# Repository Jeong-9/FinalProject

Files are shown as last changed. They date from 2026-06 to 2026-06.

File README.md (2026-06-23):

# ChemiBot - 비접촉 화학 실험 자동화 및 안전 관제 시스템





- **프로젝트명**: chemibot 비접촉 화학 실험 자동화 및 안전 관제 시스템
- **형태**: 팀 프로젝트
- **개발 인원**: 5명

## 프로젝트 개요 
유해 물질 노출 위험이 있는 화학 실험 환경에서, 연구자가 로봇팔을 원격 제어해 실험을 수행하는 비접촉 실험실 자동화 시스템

## 프로젝트 목적 
유해 화학물질 취급 과정에서 발생할 수 있는 안전사고를 예방하고, 손동작·얼굴 및 시선 추적 기반의 직관적인 인터페이스를 통해 연구자의 조작 편의성과 실험 효율을 향상시키는 것을 목표로 함

## 주요 기능
- 손동작 인식을 통한 로봇팔 제어.
- 얼굴 방향 추적을 통한 화면 내 시험관대 선택.
- 가스, 온도, 습도 기반 실시간 환경 모니터링.
- 실험실 및 보안실 모니터링 WPF 프로그램.
- React 기반 관리자 웹 화면.
- 스위치, 가스누출, 쓰러짐 감지를 통한 비상정지 기능.

# 개발 환경 및 사용 언어
- **개발 환경**: Visual Studio Code/Visual Studio
- **사용 언어**: C#, C++, Python
- **S/W 제작**: WPF, Flask, React
- **사용 라이브러리**: MediaPipe, OpenCV, RandomForest

- **통신**: TCP/IP, UDP, Socket.IO (WebSocket 기반), HTTP, UART Serial
- **임베디드 및 데이터베이스**: myCobot 280, Raspberry Pi 4B (myCobot 내장), Arduino Uno, MySQL

# 하드웨어 구성도 
 

# 시스템 구성


# 실험실 모니터링 프로그램 GUI 흐름도


# 비상 흐름도


## 담당 역할

- 실험실 아크릴 박스 3D 모델링 및 2D 제작 도면을 작성.
- 아크릴판 재단 및 실험실 아크릴 박스를 제작.
- Raspberry Pi 기반 내부문 및 잠금장치 서보모터 제어 코드를 작성.
- C# WPF 기반 보안실 모니터링 화면을 구현.
- TCP를 기반으로 실험실 웹캠 영상을 수신 받아 보안실 화면에 띄우고, UDP 기반의 비상 신호를 처리.
- UDP를 기반으로 보안실 마이크 음성을 송신해서 실험실 스피커에 출력하는 기능 구현.

## 담당 구현 파일

| 파일 | 설명 |
|---|---|
| `LabSafetyManager/MainWindow.xaml` | 보안실 WPF 화면 UI 구성 |
| `LabSafetyManager/MainWindow.xaml.cs` | 영상 출력, 비상 처리, 상태 표시, 로그, 버튼 이벤트 처리 |
| `LabSafetyManager/FallTcpClient.cs` | TCP 기반 영상 수신 및 UDP 기반 비상 신호 처리 |
| `LabSafetyManager/IntercomService.cs` | 보안실 PC 마이크 음성을 UDP 기반으로 전송 |
| `LabSafetyManager/LogEntry.cs` | 이벤트 로그의 시간, 위험 단계, 메시지 관리 |
| `Servo/door_control.py` | 내부문 및 잠금장치 서보모터 제어 |
| `Servo/door_server.py` | TCP 기반 서보모터 제어 명령 수신 |
| `lab_intercom.py` | UDP 기반 음성 수신 및 실험실 스피커 음성 출력 |

# 구현한 하드웨어 기능
## 1. 실험실 아크릴 박스 설계 및 제작 준비


- Solid Edge를 사용해 실험실 아크릴 박스의 전체 구조를 3D 모델링했습니다. 로봇팔 동작 범위와 실험 도구 배치 공간을 고려해 각 판의 크기를 설계했습니다.
## 2. 2D 설계도면 작성 


- 완성된 3D 모델링을 참고해서 각 판의 설계도면을 .dxf 파일 형식으로 변환했습니다. 각 판의 치수와 경첩 구멍 위치, 문 위치를 표시했습니다.

## 3. 아크릴 재단 및 제작


- 완성된 도면을 기준으로 아크릴판을 재단하고 실제 실험 공간을 제작했습니다. 여기서 내부 유해 물질이 외부로 빠져나가는 것을 방지하기 위해 외부 문과 내부 문으로 구성된 이중문 구조로 설계하고 제작했습니다.

## 4. 이중문 - 잠금장치, 내부 문 서보모터 제어

### 잠금장치


### 내부 문 모터


- 라즈베리파이에서 `pigpio`를 이용해 내부문 서보모터 2개와 잠금장치 서보모터를 제어했습니다.
- 내부문 1은 GPIO18, 내부문 2는 GPIO13, 잠금장치는 GPIO19에 연결했습니다.
- 각 모터의 열림·닫힘 위치를 직접 테스트하여 PWM 펄스폭 값을 설정했습니다.
- `door_server.py`는 TCP를 통해 명령을 수신하고, `door_control.py`의 서보 동작 함수와 연결합니다.
- 실험 시작, 내부문 열림·닫힘, 잠금 해제·복귀 명령을 구분하여 실행하도록 구현했습니다.
- 내부문 열림 명령이 들어올 때 잠금장치가 잠기지 않은 상태라면, 먼저 잠금장치를 잠근 뒤 내부문을 열도록 구성했습니다. 이를 통해 실험 공간이 외부에 직접 노출되지 않도록 했습니다.
- 실험 종료 후에는 내부문을 닫은 뒤 사용자가 시약관을 회수할 수 있도록 잠금 해제 명령을 별도로 구성했습니다.

# 구현한 소프트웨어 기능

## 1. 보안실 화면
### 평상시 보안실 화면


### 보안실 화면 버튼 기능

  

- 보안실 화면은 C# WPF를 활용하여 제작했습니다.
- 중앙 카메라 영역은 실험실 측 PC에서 전송한 웹캠 영상을 TCP로 수신하여 실시간으로 출력합니다.
- 이벤트 로그는 TCP 연결, 비상 감지, 경고 해제, 음성 송신 등 주요 이벤트를 시간 순서대로 기록합니다. 정보·주의·위험 단계에 따라 색상을 구분하여 표시합니다.
- 시스템 상태에서 카메라 연결 상태와 비상 상태 여부를 확인할 수 있습니다.
- 버튼 기능에서 경고 해제 버튼을 누르면 보안실 WPF의 비상 화면과 사이렌을 종료하고, UDP로 비상 해제(clear) 신호를 전송하여 통제실 감지 상태를 초기화합니다
- 로그 저장 버튼은 이벤트 로그에 기록된 모든 상태와 감지 시각을 .txt 파일로 저장할 수 있습니다.

## 2. 비상상황 발생 시 비상 신호 수신 및 음성 안내
### 비상 상황 발생 시 보안실 화면
  

### 보안실 관리자의 마이크 음성 안내
  

- 비상상황 발생 시 보안실 PC와 연결된 마이크를 통해 안내방송을 할 수 있습니다. 이 음성은 보안실에서 실험실 스피커로 전달되도록 구현했습니다.
- 비상 신호는 UDP로 수신하며, GAS_SENSOR, EME_BUTTON, FALL_DOWN 값을 통해 가스 감지, 비상 버튼, 쓰러짐 감지를 구분합니다.
- 실험실의 lab_intercom.py는 UDP로 수신한 보안실 음성을 실험실 스피커로 출력하도록 구현했습니다.
- 비상상황이 종료되면, 보안실 마이크 음성 수신도 종료되도록 구현했습니다.

# 시연 영상
https://youtu.be/Ujo4n_t4xfY

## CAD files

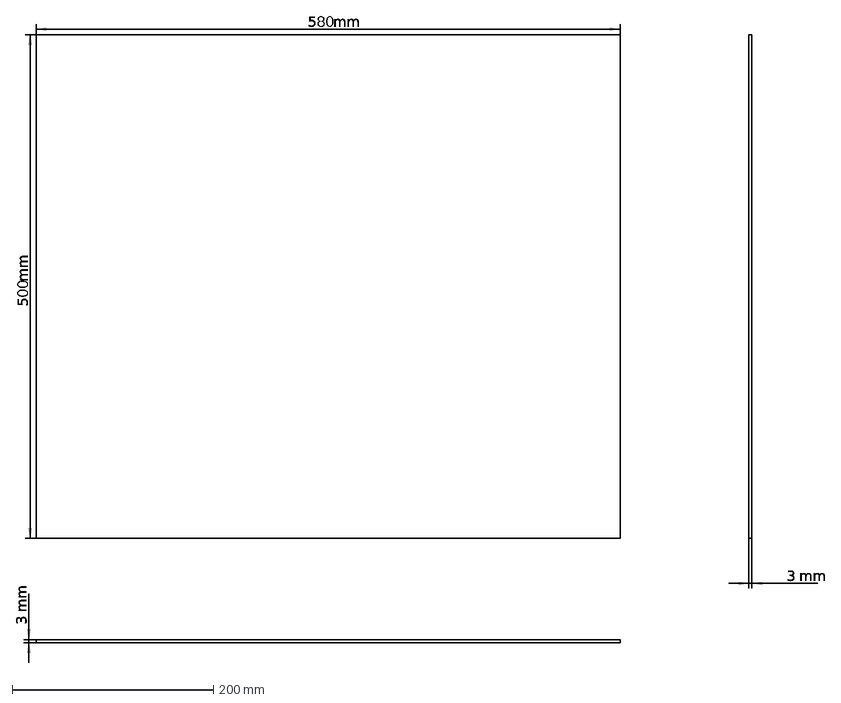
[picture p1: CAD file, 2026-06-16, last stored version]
Acrylic Plate Design Chart/아크릴 판 옆면.dxf
580
mm
500
3

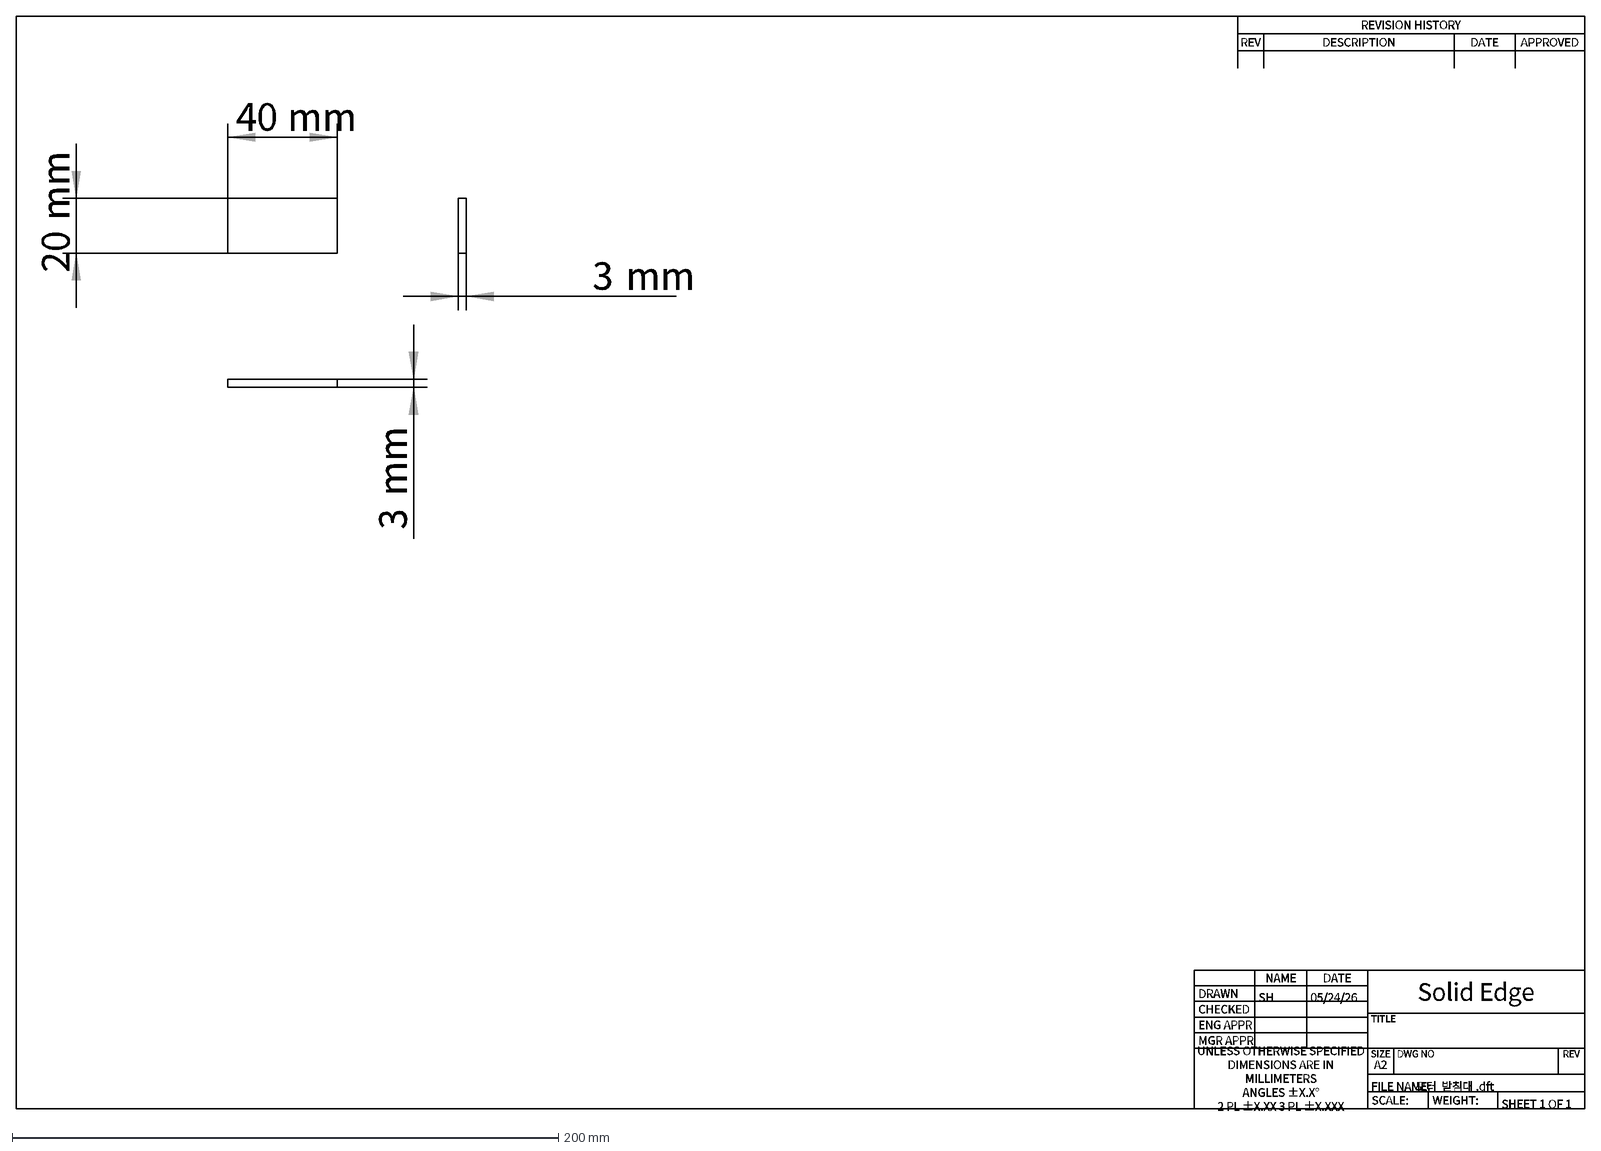
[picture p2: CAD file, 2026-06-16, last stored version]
모터 받침대.dxf
40
mm
20
3
DRAWN
CHECKED
ENG APPR
MGR APPR
UNLESS OTHERWISE SPECIFIED DIMENSIONS ARE IN MILLIMETERS ANGLES ±X.X° 2 PL ±X.XX 3 PL ±X.XXX
NAME
SH
DATE
05/24/26
Solid Edge
TITLE
SIZE
A2
DWG NO
REV
FILE NAME:
모터
받침대
.dft
SCALE:
WEIGHT:
SHEET 1 OF 1
REVISION HISTORY
DESCRIPTION
APPROVED

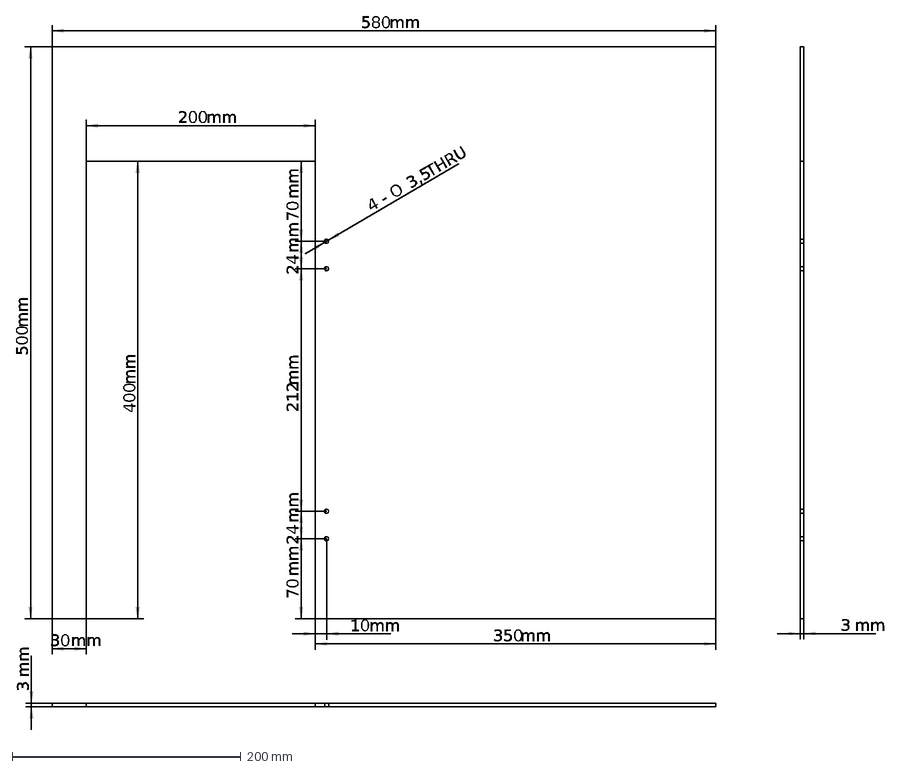
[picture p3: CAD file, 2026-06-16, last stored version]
Acrylic Plate Design Chart/아크릴 판 이중 문 구멍.dxf
580
mm
500
30
200
400
O
3,5
4 -
THRU
70
24
212
3
350
10

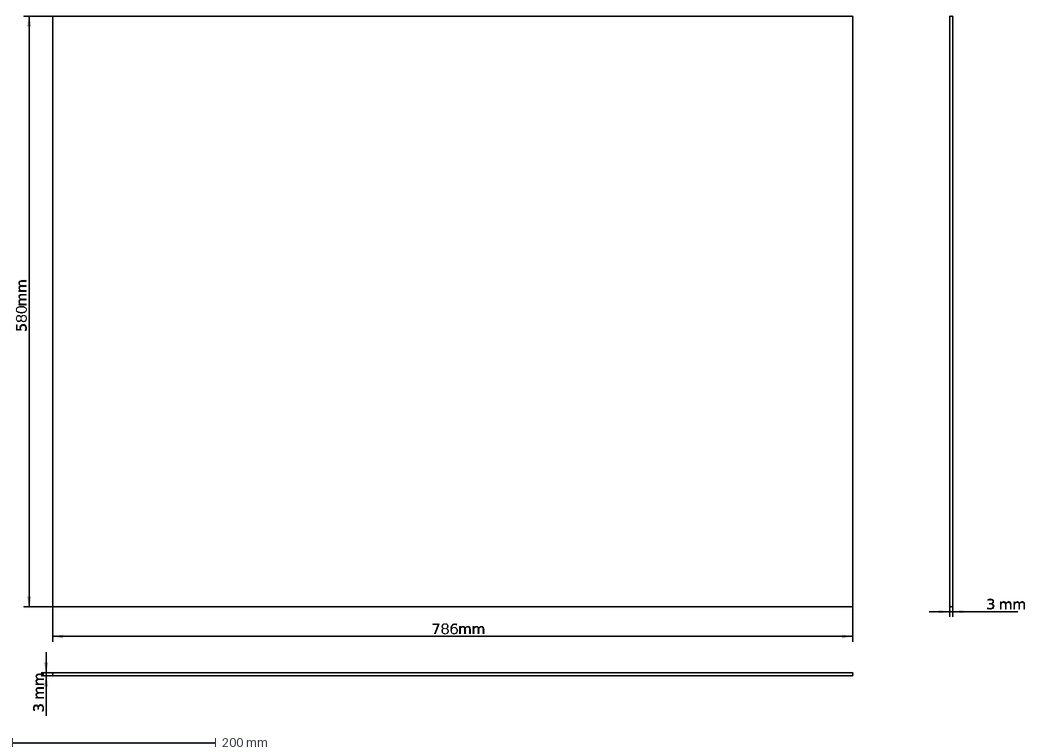
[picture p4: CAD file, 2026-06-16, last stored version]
Acrylic Plate Design Chart/아크릴 판 윗면.dxf
786
mm
580
3

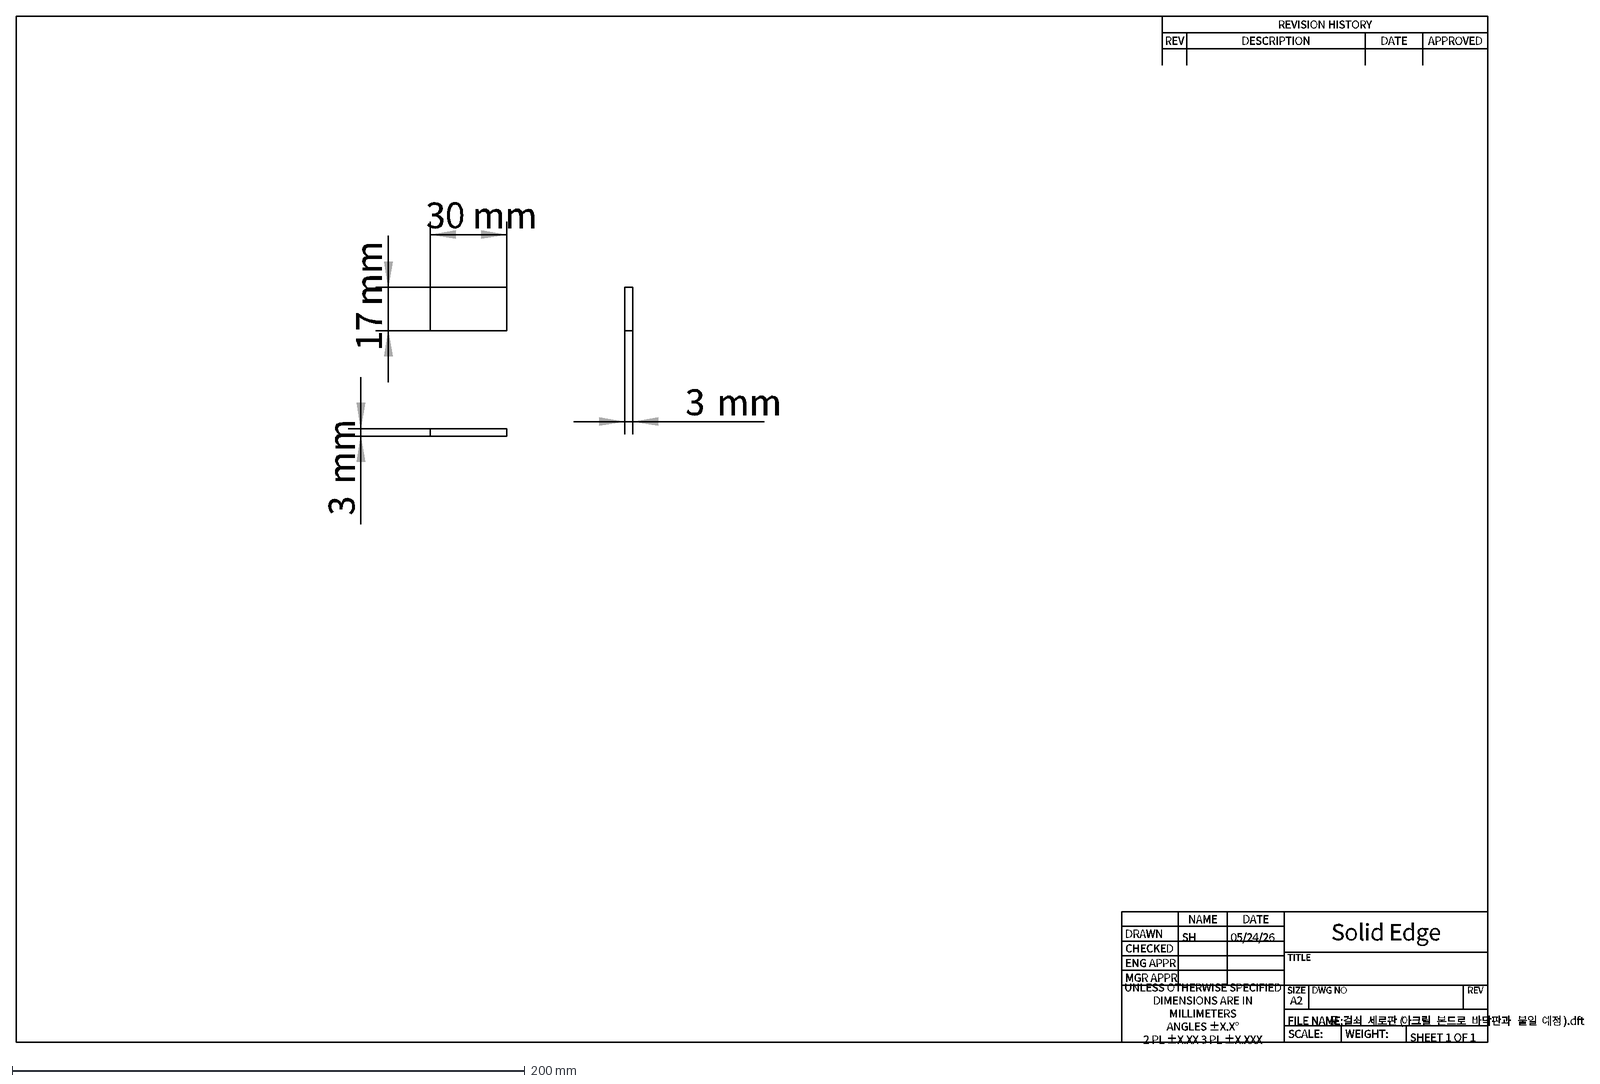
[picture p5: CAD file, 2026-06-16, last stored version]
Acrylic Plate Design Chart/문 걸쇠 세로판(아크릴 본드로 바닥판과 붙일 예정).dxf
30
mm
17
3
DRAWN
CHECKED
ENG APPR
MGR APPR
UNLESS OTHERWISE SPECIFIED DIMENSIONS ARE IN MILLIMETERS ANGLES ±X.X° 2 PL ±X.XX 3 PL ±X.XXX
NAME
SH
DATE
05/24/26
Solid Edge
TITLE
SIZE
A2
DWG NO
REV
FILE NAME:
문
걸쇠
세로판
(
아크릴
본드로
바닥판과
붙일
예정
).dft
SCALE:
WEIGHT:
SHEET 1 OF 1
REVISION HISTORY
DESCRIPTION
APPROVED

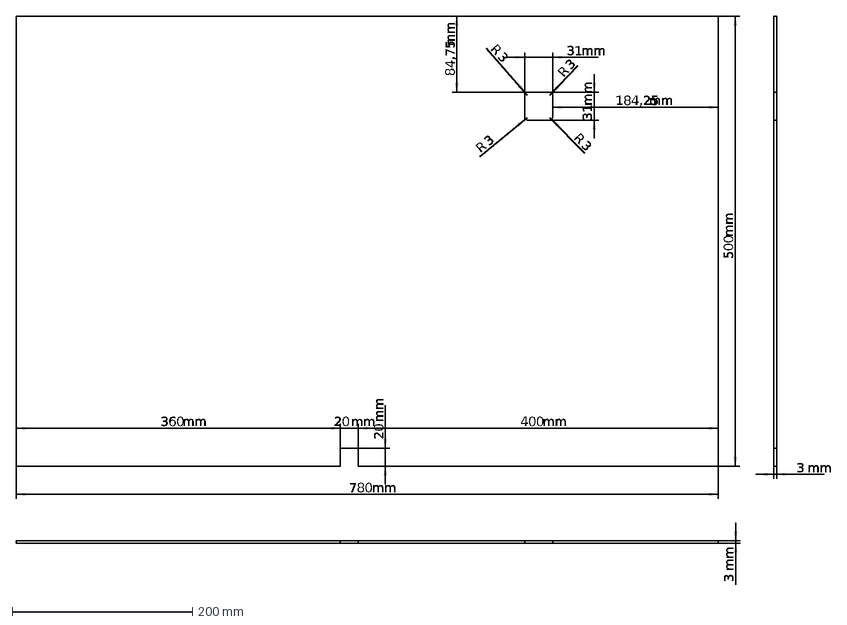
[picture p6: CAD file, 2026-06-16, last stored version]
Acrylic Plate Design Chart/아크릴 판 뒷면.dxf
360
mm
400
20
31
R
3
184,25
84,75
500
780

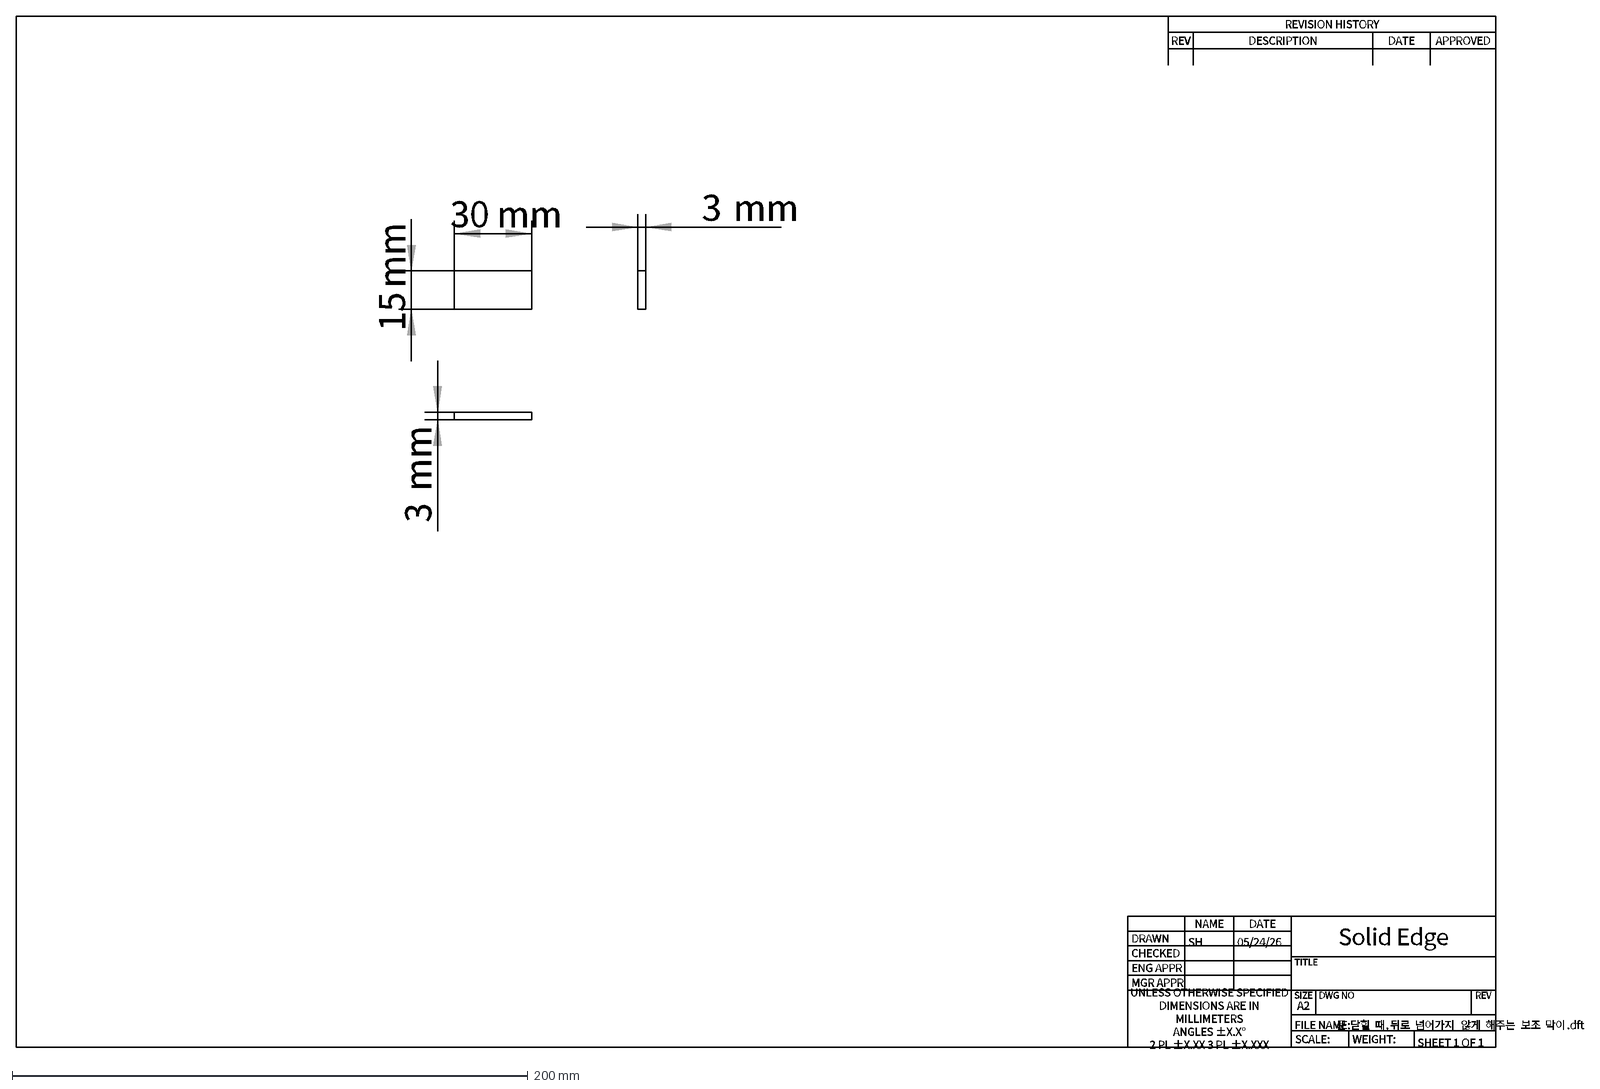
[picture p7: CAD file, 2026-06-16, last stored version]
Acrylic Plate Design Chart/문 닫힐 때, 뒤로 넘어가지 않게 해주는 보조 막이.dxf
30
mm
15
3
DRAWN
CHECKED
ENG APPR
MGR APPR
UNLESS OTHERWISE SPECIFIED DIMENSIONS ARE IN MILLIMETERS ANGLES ±X.X° 2 PL ±X.XX 3 PL ±X.XXX
NAME
SH
DATE
05/24/26
Solid Edge
TITLE
SIZE
A2
DWG NO
REV
FILE NAME:
문
닫힐
때
,
뒤로
넘어가지
않게
해주는
보조
막이
.dft
SCALE:
WEIGHT:
SHEET 1 OF 1
REVISION HISTORY
DESCRIPTION
APPROVED

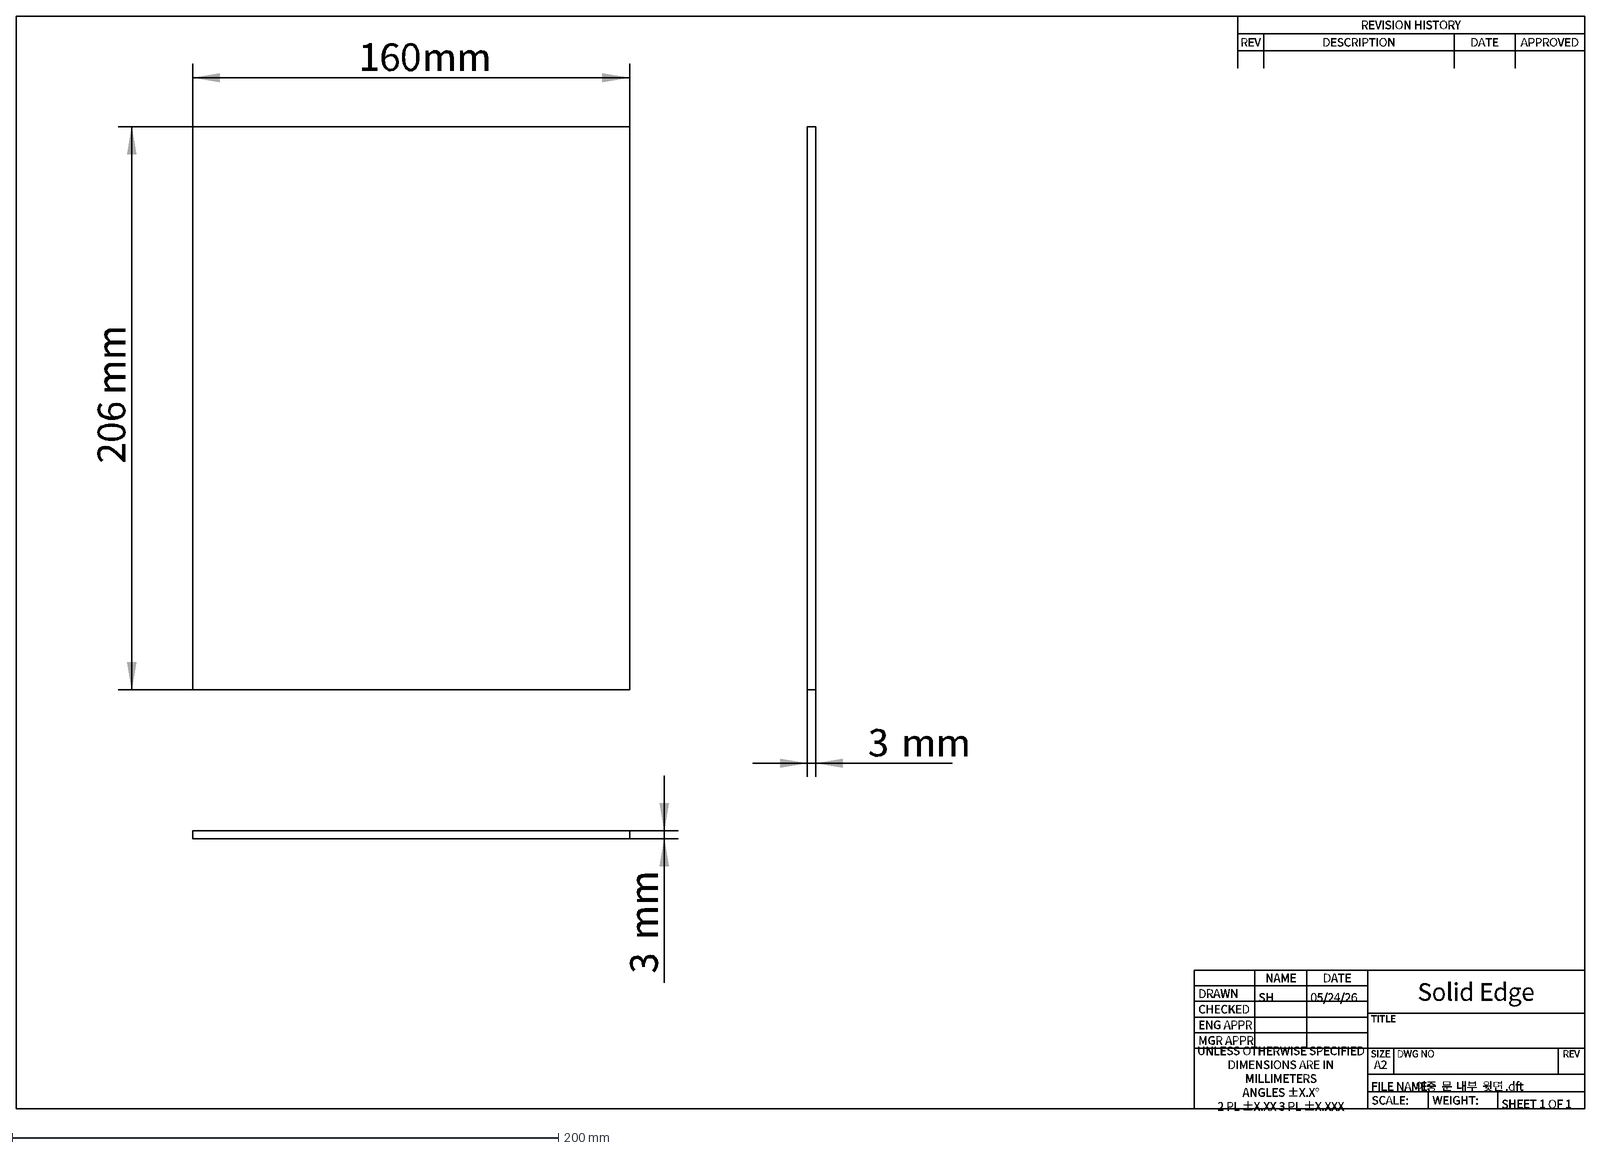
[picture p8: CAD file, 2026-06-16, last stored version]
Acrylic Plate Design Chart/이중 문 내부 윗면.dxf
160
mm
206
3
DRAWN
CHECKED
ENG APPR
MGR APPR
UNLESS OTHERWISE SPECIFIED DIMENSIONS ARE IN MILLIMETERS ANGLES ±X.X° 2 PL ±X.XX 3 PL ±X.XXX
NAME
SH
DATE
05/24/26
Solid Edge
TITLE
SIZE
A2
DWG NO
REV
FILE NAME:
이중
문
내부
윗면
.dft
SCALE:
WEIGHT:
SHEET 1 OF 1
REVISION HISTORY
DESCRIPTION
APPROVED

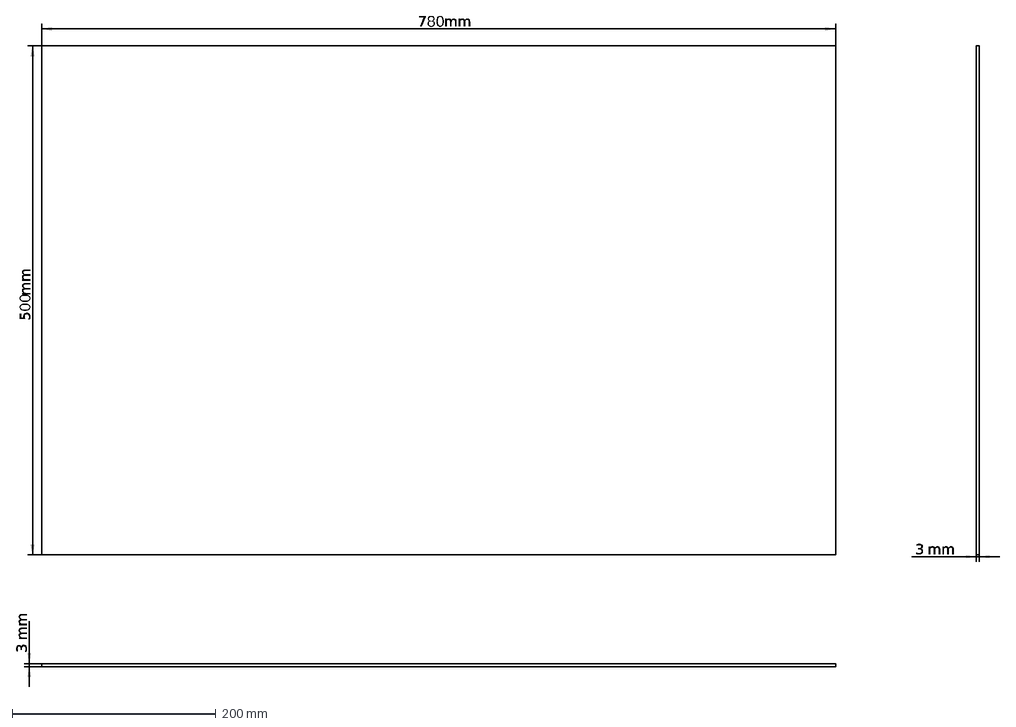
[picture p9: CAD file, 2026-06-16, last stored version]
Acrylic Plate Design Chart/아크릴 판 앞면.dxf
780
mm
500
3

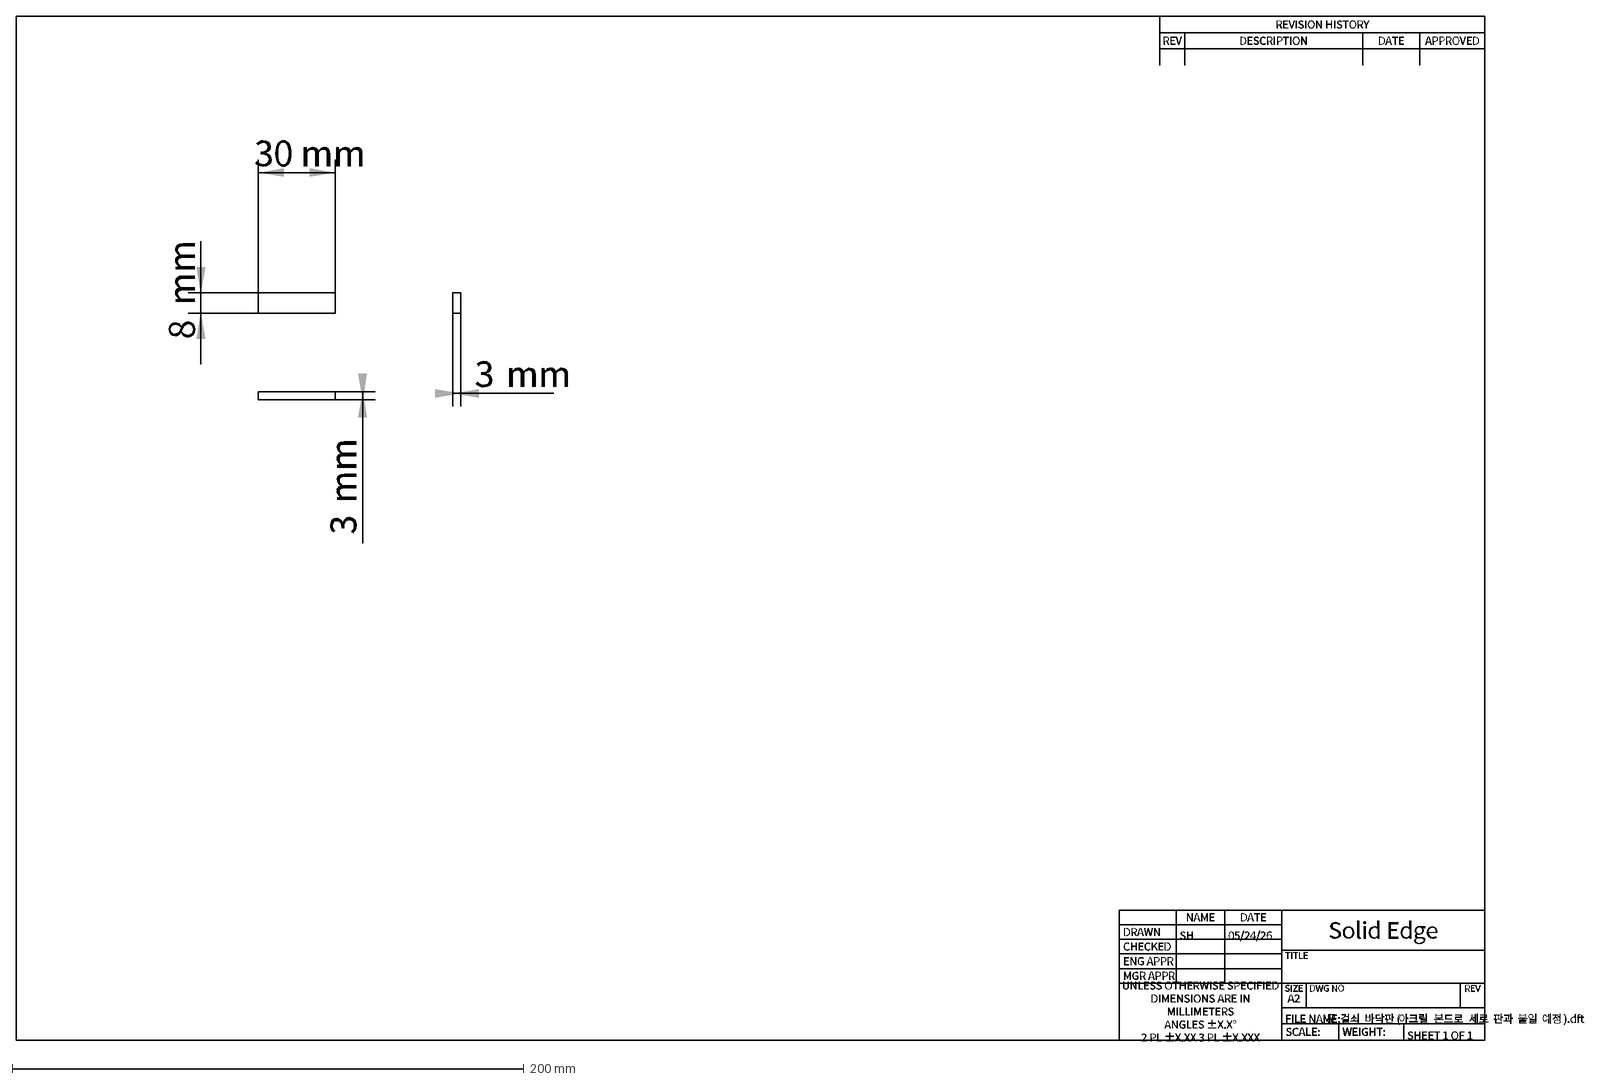
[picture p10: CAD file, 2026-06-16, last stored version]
Acrylic Plate Design Chart/문 걸쇠 바닥판(아크릴 본드로 세로 판과 붙일 예정).dxf
30
mm
8
3
DRAWN
CHECKED
ENG APPR
MGR APPR
UNLESS OTHERWISE SPECIFIED DIMENSIONS ARE IN MILLIMETERS ANGLES ±X.X° 2 PL ±X.XX 3 PL ±X.XXX
NAME
SH
DATE
05/24/26
Solid Edge
TITLE
SIZE
A2
DWG NO
REV
FILE NAME:
문
걸쇠
바닥판
(
아크릴
본드로
세로
판과
붙일
예정
).dft
SCALE:
WEIGHT:
SHEET 1 OF 1
REVISION HISTORY
DESCRIPTION
APPROVED

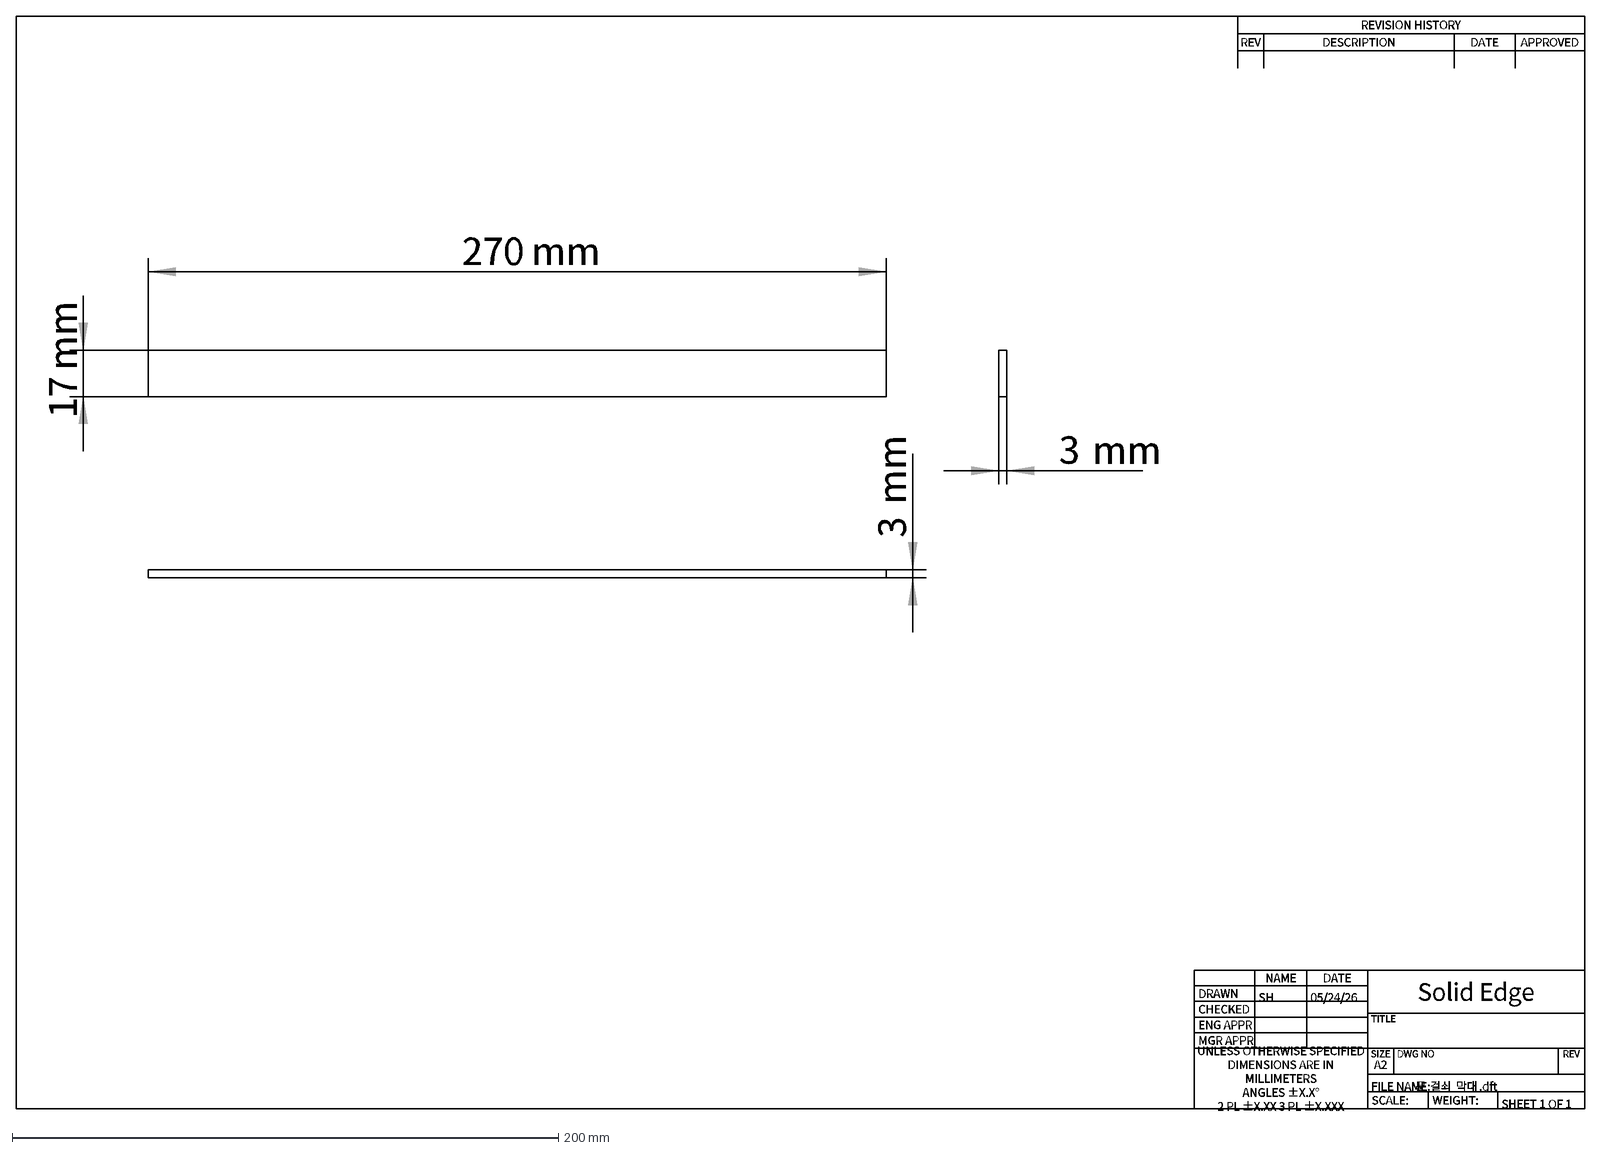
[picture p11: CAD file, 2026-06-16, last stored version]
Acrylic Plate Design Chart/문 걸쇠 막대.dxf
270
mm
17
3
DRAWN
CHECKED
ENG APPR
MGR APPR
UNLESS OTHERWISE SPECIFIED DIMENSIONS ARE IN MILLIMETERS ANGLES ±X.X° 2 PL ±X.XX 3 PL ±X.XXX
NAME
SH
DATE
05/24/26
Solid Edge
TITLE
SIZE
A2
DWG NO
REV
FILE NAME:
문
걸쇠
막대
.dft
SCALE:
WEIGHT:
SHEET 1 OF 1
REVISION HISTORY
DESCRIPTION
APPROVED

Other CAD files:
Acrylic Plate Design Chart/이중 문 내부 벽면.dxf
Acrylic Plate Design Chart/이중 문(외벽 문).dxf
Acrylic Plate Design Chart/이중 문 내부 벽면2.dxf

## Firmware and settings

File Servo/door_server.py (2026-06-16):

import socket
import threading
from doors.door_control import ServoController

PORT = 9003                      # WPF가 서보 명령 보내는 포트

servo = ServoController()        # 서보 컨트롤러 인스턴스 (전역 — 모든 명령이 여기 거쳐감)


def handle(conn):
    # 클라이언트(WPF)로부터 명령 수신 후 해당 서보 동작 실행
    try:
        data = conn.recv(1024).decode().strip()  # 명령 문자열 수신
        print(f"[ServoServer] 수신: {data}")

        # 서보 동작은 시간이 걸리는 blocking 작업
        # 별도 스레드로 실행해야 다음 명령 바로 받을 수 있음
        if data == "EXP_START":
            threading.Thread(target=servo.experiment_start, daemon=True).start()
        elif data == "DOOR_OPEN":
            threading.Thread(target=servo.open_for_robot,   daemon=True).start()
        elif data == "DOOR_CLOSE":
            threading.Thread(target=servo.close_for_robot,  daemon=True).start()
        elif data == "LOCK_OPEN":
            threading.Thread(target=servo.lock_open,        daemon=True).start()
        elif data == "LOCK_CLOSE":
            threading.Thread(target=servo.lock_close,       daemon=True).start()
        elif data == "EXP_END":
            threading.Thread(target=servo.end_experiment,   daemon=True).start()
        else:
            print(f"[ServoServer] 알 수 없는 명령: {data}")

    finally:
        conn.close()             # 처리 완료 후 연결 종료


def start():
    # 포트 9003에서 WPF 명령 대기
    # main.py에서 스레드로 호출됨
    s = socket.socket(socket.AF_INET, socket.SOCK_STREAM)
    s.setsockopt(socket.SOL_SOCKET, socket.SO_REUSEADDR, 1)  # 재시작 시 포트 재사용
    s.bind(("0.0.0.0", PORT))
    s.listen(5)
    print(f"[ServoServer] 대기중 — {PORT}번 포트")

    while True:
        try:
            conn, addr = s.accept()                          # 연결 수락
            threading.Thread(target=handle, args=(conn,), daemon=True).start()  # 연결마다 스레드 처리
        except Exception as e:
            print(f"[ServoServer] 오류: {e}")


if __name__ == "__main__":
    start()

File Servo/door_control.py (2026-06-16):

import pigpio
import threading
from time import sleep

# ── GPIO 핀 번호 (BCM 기준) ──
SERVO1     = 18    # 내부문 1번 (물리핀 12)
SERVO2     = 13    # 내부문 2번 (물리핀 33)
LOCK_SERVO = 19    # 잠금장치   (물리핀 35)

# ── 서보 위치값 (마이크로초) ──
# pigpio 범위 : 500 ~ 2500  /  1500 = 중간(90도)
SERVO1_OPEN  = 2500    # 내부문1 열림
SERVO1_CLOSE = 700     # 내부문1 닫힘
SERVO2_OPEN  = 600     # 내부문2 열림
SERVO2_CLOSE = 1850    # 내부문2 닫힘
LOCK_HOME    = 2300    # 잠금 해제 위치
LOCK_LOCKED  = 1300    # 잠금 위치

# ── 이동 속도 설정 ──
# step  : 한 번에 이동할 펄스 크기  → 클수록 빠름
# delay : 스텝 사이 대기 시간(초)   → 작을수록 빠름
DOOR_OPEN_STEP   = 10
DOOR_OPEN_DELAY  = 0.02
DOOR_CLOSE_STEP  = 15
DOOR_CLOSE_DELAY = 0.012
LOCK_STEP        = 20
LOCK_DELAY       = 0.01


def limit_pulse(value):
    # 펄스값이 500~2500 범위를 벗어나면 서보/기구 파손 가능
    # 항상 이동 전에 범위 제한
    return max(400, min(3000, value))


class ServoController:
    # 잠금장치 + 내부문 통합 제어
    #
    # 시작 가정:
    #   내부문 → 닫혀있음
    #   잠금   → 열려있음 (LOCK_HOME)
    #
    # 상태 흐름:
    #   실험시작  : 잠금=잠김  내부문=닫힘  (experiment_start)
    #   로봇접근  : 잠금=잠김  내부문=열림  (open_for_robot)
    #   로봇완료  : 잠금=잠김  내부문=닫힘  (close_for_robot)
    #   잠금해제  : 잠금=열림  내부문=닫힘  (lock_open)
    #   잠금복귀  : 잠금=잠김  내부문=닫힘  (lock_close)
    #   실험종료  : 잠금=잠김  내부문=닫힘  (end_experiment)

    def __init__(self):
        self.pi = pigpio.pi()                    # pigpio 데몬 연결 (sudo pigpiod 먼저 실행)
        if not self.pi.connected:
            raise RuntimeError("pigpiod 연결 실패 — sudo pigpiod 먼저 실행!")

        self._mutex = threading.Lock()           # 동시에 여러 명령 들어와도 순서대로 처리

        # 시작 가정값 (experiment_start 호출로 실제 위치 맞춤)
        self.cur1     = SERVO1_CLOSE             # 내부문1 현재 위치
        self.cur2     = SERVO2_CLOSE             # 내부문2 현재 위치

        self.cur_lock = LOCK_HOME                # 잠금장치 현재 위치

    # ────────────────────────────────────────
    # 내부 이동 함수 (외부에서 직접 호출 금지)
    # ────────────────────────────────────────

    def _move_doors(self, target1, target2, step, delay):
        target1 = limit_pulse(target1)           # 목표 펄스 범위 제한
        target2 = limit_pulse(target2)

        diff1 = target1 - self.cur1              # 내부문1 이동해야 할 거리
        diff2 = target2 - self.cur2              # 내부문2 이동해야 할 거리
        max_d = max(abs(diff1), abs(diff2))      # 둘 중 더 긴 이동거리 기준으로 스텝 계산

        if max_d == 0:                           # 이미 목표 위치면 이동 생략
            print("[서보] 문: 이미 해당 위치 — 생략")
            return

        start1      = self.cur1
        start2      = self.cur2
        total_steps = max(1, int(max_d / step))  # 총 스텝 수 계산

        for n in range(1, total_steps + 1):
            ratio = n / total_steps              # 0~1 비율로 두 문이 동시에 시작·끝남
            self.pi.set_servo_pulsewidth(SERVO1, int(start1 + diff1 * ratio))
            self.pi.set_servo_pulsewidth(SERVO2, int(start2 + diff2 * ratio))
            sleep(delay)

        # 마지막 위치 정확히 확정
        self.pi.set_servo_pulsewidth(SERVO1, target1)
        self.pi.set_servo_pulsewidth(SERVO2, target2)
        self.cur1 = target1                      # 현재 위치 업데이트
        self.cur2 = target2

    def _move_lock(self, target):
        target = limit_pulse(target)             # 목표 펄스 범위 제한
        start  = self.cur_lock

        if target >= start:                      # 목표가 크면 정방향
            pulse_range = range(start, target + 1, LOCK_STEP)
        else:                                    # 목표가 작으면 역방향
            pulse_range = range(start, target - 1, -LOCK_STEP)

        for pulse in pulse_range:
            self.pi.set_servo_pulsewidth(LOCK_SERVO, pulse)
            sleep(LOCK_DELAY)

        # 마지막 위치 정확히 확정
        self.pi.set_servo_pulsewidth(LOCK_SERVO, target)
        self.cur_lock = target                   # 현재 위치 업데이트

    def is_locked(self):
        """잠금 상태 (True=잠김)"""
        return self.cur_lock == LOCK_LOCKED

    # ────────────────────────────────────────
    # 공개 명령
    # ────────────────────────────────────────

    def experiment_start(self):
        # [EXP_START] 실험 시작 — 내부문 닫기 + 잠금
        with self._mutex:
            print("[서보] ▶ 실험 시작 — 내부문 닫기")
            # 단계 이동 없이 바로 닫힘 위치로 (벌컥 방지)
            self.pi.set_servo_pulsewidth(SERVO1, SERVO1_CLOSE)
            self.pi.set_servo_pulsewidth(SERVO2, SERVO2_CLOSE)
            self.cur1 = SERVO1_CLOSE
            self.cur2 = SERVO2_CLOSE
            sleep(0.5)
            print("[서보] ▶ 잠금 적용")
            self._move_lock(LOCK_LOCKED)
            sleep(0.3)
            self.pi.set_servo_pulsewidth(LOCK_SERVO, 0)
            print("[서보] ▶ 잠금 완료")

    def open_for_robot(self):
        # [DOOR_OPEN] 로봇 접근 — 내부문 열기
        # 인터록: 잠금이 열려있으면 먼저 잠금 후 내부문 열기
        with self._mutex:
            print("[서보] ▶ 로봇 접근 — 내부문 열기")

            if self.cur_lock != LOCK_LOCKED:     # 잠금이 해제 상태면
                print("[서보] ⚠ 인터록 — 잠금 먼저")
                self._move_lock(LOCK_LOCKED)     # 먼저 잠금
                sleep(0.3)
                self.pi.set_servo_pulsewidth(LOCK_SERVO, 0)  # 토크 해제
                sleep(0.5)                       # 잠금 안정화 대기

            self._move_doors(SERVO1_OPEN, SERVO2_OPEN,
                             DOOR_OPEN_STEP, DOOR_OPEN_DELAY)
            print("[서보] ▶ 내부문 열림")

    def close_for_robot(self):
        # [DOOR_CLOSE] 로봇 완료 후 내부문 닫기
        with self._mutex:
            print("[서보] ▶ 로봇 완료 — 내부문 닫기")
            self._move_doors(SERVO1_CLOSE, SERVO2_CLOSE,
                             DOOR_CLOSE_STEP, DOOR_CLOSE_DELAY)
            print("[서보] ▶ 내부문 닫힘")

    def lock_open(self):
        # [LOCK_OPEN] 사용자 시약관 접근 — 잠금 해제
        with self._mutex:
            print("[서보] ▶ 잠금 해제")
            self._move_doors(SERVO1_CLOSE, SERVO2_CLOSE,
                             DOOR_CLOSE_STEP, DOOR_CLOSE_DELAY)
            self._move_lock(LOCK_HOME)
            print("[서보] ▶ 잠금 해제 완료")

    def lock_close(self):
        # [LOCK_CLOSE] 사용자 접근 완료 — 잠금
        with self._mutex:
            print("[서보] ▶ 잠금 복귀")
            self._move_lock(LOCK_LOCKED)
            sleep(0.3)
            self.pi.set_servo_pulsewidth(LOCK_SERVO, 0)
            print("[서보] ▶ 잠금 완료")

    def end_experiment(self):
        # [EXP_END] 실험 종료
        with self._mutex:
            print("[서보] ▶ 실험 종료 — 내부문 닫기")
            self._move_doors(SERVO1_CLOSE, SERVO2_CLOSE,
                             DOOR_CLOSE_STEP, DOOR_CLOSE_DELAY)
            print("[서보] ▶ 종료 완료")

    def stop(self):
        # 프로그램 종료 시 서보 토크 해제 + pigpio 연결 해제
        self.pi.set_servo_pulsewidth(SERVO1, 0)
        self.pi.set_servo_pulsewidth(SERVO2, 0)
        self.pi.set_servo_pulsewidth(LOCK_SERVO, 0)
        self.pi.stop()
        print("[서보] 연결 종료")
